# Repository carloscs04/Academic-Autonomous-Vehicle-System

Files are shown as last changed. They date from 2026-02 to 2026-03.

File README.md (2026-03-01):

# Car Controller System

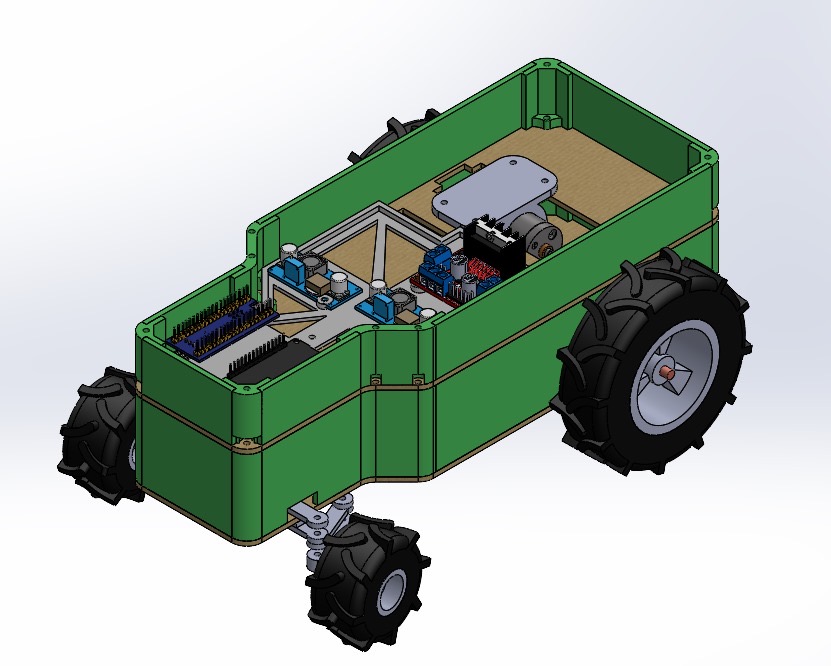
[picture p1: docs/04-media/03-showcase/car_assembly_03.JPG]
Car Assembly


---

## Academic Challenge Context

This project was developed as part of an academic robotics challenge with the following core requirements:

- 4-wheel vehicle (Ackermann or differential drive)
- At least one PID-controlled system (velocity or orientation)
- Modifiable velocity reference
- Autonomous square trajectory (X meters per side, 5 m < X < 20 m)
- 10-second stop at each waypoint
- Return to starting position
- Telemetry transmission to an external system
- Battery-powered operation
- Clean mechanical presentation

---

## Project Approach

Although the challenge did not require designing the vehicle from scratch, our team decided to build the car completely from zero for learning purposes.

This included:

- Mechanical chassis design and assembly
- Motor and driver integration
- Sensor architecture definition
- Multi-microcontroller firmware development
- Inter-board communication
- Control system implementation

The objective was to understand the system at a full engineering level rather than relying on pre-built platforms.

---

## Repository Structure

### docs/

Project documentation organized by development phase:

- research → references and background study  
- design → system architecture and decisions  
- testing → validation results  
- reports → academic deliverables  
- media → images and videos  
- development-history → progress tracking  

---

### firmware/

Embedded software for each microcontroller:

- esp32 → high-level control, navigation logic, telemetry  
- stm32 → magnetometer acquisition and sensor interface  

Each subfolder contains board-specific configuration and build instructions.

---

### hardware/

Physical system design files:

- cad → mechanical design files  

---

## System Summary

The final system integrates:

- Sensor acquisition (STM32)
- Control and navigation logic (ESP32)
- PID control implementation
- Autonomous trajectory tracking
- Telemetry transmission
- Fully battery-powered operation

The project fulfills the academic requirements while extending the implementation to a complete custom-built embedded system.

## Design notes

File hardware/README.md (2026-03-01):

# Final Mechanical Structure

This folder contains the **final validated CAD models** of the vehicle’s mechanical architecture.  
These files represent the approved structural configuration intended for manufacturing, integration, and full system validation.

This release defines the stable mechanical baseline of the project.

---

## Folder Overview

- **assembly** — Complete mechanical assemblies ready for integration and validation.
- **full_vehicle** — High-level CAD model of the entire vehicle structure.
- **parts** — Individual finalized mechanical components used in the assemblies.

---

## Design Intent

The final structure was developed considering:

- Structural stability under expected operational loads  
- Modular integration with electronics and firmware  
- Manufacturability and assembly feasibility  
- Accessibility for maintenance and testing  
- Mechanical alignment with control system requirements  

---

## Release Status

This directory represents the **approved mechanical release**.  
Experimental models and intermediate iterations are stored outside this folder.

Any modification to the structure must be version-controlled and documented.

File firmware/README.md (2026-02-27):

# Car Controller – Firmware Layer

## Overview

This directory contains all embedded firmware used in the Car Controller system.

The system is composed of two microcontrollers:

- ESP32 → High-level control and communication
- STM32 → Magnetometer acquisition and sensor interface

The firmware layer is divided by board type to clearly separate responsibilities.

---

## Architecture Overview

The system follows a distributed architecture:

ESP32
  ├─ Bluetooth gamepad interface
  ├─ Manual / Autonomous control logic
  ├─ Motor and servo control
  ├─ Ultrasonic sensing
  ├─ WiFi + MQTT telemetry
  └─ Receives heading data from STM32 via UART

STM32
  ├─ I2C communication with magnetometer
  ├─ Raw magnetic field acquisition (X, Y, Z)
  ├─ Offset calibration
  ├─ ASCII data formatting
  └─ Transmits heading data via USB CDC and UART

The STM32 acts as a dedicated sensor node.  
The ESP32 acts as the system controller.

---

## Folder Structure
firmware/
├── esp32/
│ └── Car-Controller-ESP32/
│
└── stm32/
└── Car-Controller-STM32/

Each subfolder contains:

- Source code
- Board configuration
- Peripheral setup
- Individual README

---

## Communication Flow

1. STM32 reads magnetometer via I2C.
2. STM32 applies calibration.
3. STM32 sends formatted X, Y, Z values via UART.
4. ESP32 receives heading data.
5. ESP32 uses heading for autonomous navigation.
6. ESP32 optionally sends telemetry to cloud.

---

## Design Philosophy

The firmware is divided by responsibility:

STM32 → Deterministic sensor acquisition  
ESP32 → Behavioral control and communication  

This separation improves:

- Modularity
- Debugging
- Scalability
- System clarity

---

## Development Tools

ESP32:
- Arduino IDE
- ESP32 board package
- Bluepad32
- Ubidots MQTT library

STM32:
- STM32CubeIDE
- STM32CubeMX
- HAL drivers

---

## System Capabilities

- Manual driving via Bluetooth gamepad
- Autonomous navigation using magnetometer + ultrasonic
- Encoder-based displacement measurement
- USB and UART debugging
- Cloud telemetry (optional)

---

## Future Improvements

- Refactor STM32 into modular sensor driver
- Implement non-blocking communication
- Add checksum or framing protocol between boards
- Replace ASCII with binary packet format
- Introduce PID steering control
- Separate application logic from hardware layer

---

## System Summary

The firmware layer represents the embedded core of the project.

It integrates:

- Sensor acquisition
- Control logic
- Actuation
- Communication
- Telemetry

This modular multi-MCU architecture reflects scalable embedded system design principles.

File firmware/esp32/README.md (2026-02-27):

# Car Controller – ESP32 Firmware

## Overview

This firmware runs on an ESP32 and implements a car control system with:

- Bluetooth gamepad control (Bluepad32)
- Manual and autonomous driving modes
- Ultrasonic distance sensing
- Magnetometer-based orientation control (via UART from STM32)
- Quadrature encoder feedback
- Servo steering control
- Motor PWM control
- Optional WiFi + MQTT telemetry using Ubidots

The ESP32 acts as the high-level controller of the vehicle.

---

## Hardware Requirements

- ESP32 Dev Module
- DC motor with driver stage
- Steering servo
- Ultrasonic sensor (HC-SR04 type)
- Quadrature encoder
- External STM32 (magnetometer via UART)
- WiFi network (for telemetry)

---

## Pin Configuration

| Function | GPIO |
|---|---|
| Servo | 12 |
| Ultrasonic Trigger | 14 |
| Ultrasonic Echo | 27 |
| Motor Forward | 26 |
| Motor Backward | 25 |
| Motor PWM (LEDC ch2)  | 33 |
| UART2 RX (STM32 TX) | 16 |
| UART2 TX (STM32 RX) | 17 |
| Encoder Channel A | 19 |
| Encoder Channel B | 18 |

---

## Software Dependencies

Install the following libraries in Arduino IDE:

- Bluepad32
- ESP32Servo
- UbidotsEsp32Mqtt
- ESP32 Board Support Package
- WiFi (included in ESP32 core)

---

## Functional Description

### Bluetooth Control

- Supports up to 4 controllers.
- Reads joystick axes, brake, throttle and buttons.
- Buttons toggle:
  - Automatic mode
  - WiFi telemetry
  - Autonomous start

---

### Manual Mode (Control)

In manual mode:

- Steering controlled by left joystick X-axis.
- Motor direction and speed controlled by throttle and brake.
- Encoder displacement computed.
- Optional telemetry sent to Ubidots.

---

### Autonomous Mode (Automatico)

In automatic mode:

- Ultrasonic sensor measures obstacle distance.
- Magnetometer heading received via UART.
- Proportional steering correction applied.
- Directional state machine:
  - North
  - East
  - South
  - West
- Obstacle avoidance sequence executed when needed.

---

### Sensors

#### Ultrasonic

Distance calculation:

distance = (duration × sound_speed) / 2

Sound speed constant:
0.034 cm/µs

---

#### Encoder

Quadrature decoding using interrupts.

Displacement:

displacement = (pulses / pulses_per_rev) × wheel_perimeter

---

#### Magnetometer

Data received from STM32 via UART in CSV format:

X,Y,Z

Heading calculated using:

atan2(Y, X)

Normalized to 0–360 degrees.

---

### Telemetry (Optional)

When enabled:

- Connects to WiFi
- Publishes to Ubidots:
  - Heading
  - Encoder displacement
  - Ultrasonic distance

Publishing frequency controlled by PUBLISH_FREQUENCY.

---

## Build Instructions

1. Install Arduino IDE
2. Install ESP32 board support
3. Install required libraries
4. Open Car-Controller-ESP32.ino
5. Select correct ESP32 board
6. Upload at 115200 baud

---

## Configuration Notes

- WiFi credentials are hardcoded
- Ubidots token is hardcoded
- For production use, move credentials to a separate configuration file

---

## Architecture Summary

The firmware is organized into:

- Input processing
- State management
- Control logic
- Actuation
- Optional telemetry

The ESP32 handles high-level control and communication.

---

## Known Limitations

- Uses blocking delays
- Credentials stored in plain text
- Proportional control only (no PID)
- Single-loop architecture

---

## Future Improvements

- Replace delay() with non-blocking timing
- Implement full PID control
- Move configuration to external file
- Separate tasks using FreeRTOS
- Refactor state machine for modularity

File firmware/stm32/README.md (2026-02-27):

# Car Controller – STM32 Magnetometer Firmware

## Overview

This firmware runs on an STM32F1 microcontroller and performs:

- I2C communication with a 3-axis magnetometer
- Raw magnetic field acquisition (X, Y, Z)
- Offset compensation (manual calibration gaps)
- ASCII formatting of axis data
- Data transmission via:
  - USB CDC (Virtual COM Port)
  - UART2 @ 115200 baud

The STM32 acts as a **sensor acquisition and communication layer** for the system.

---

## System Architecture Role

This firmware represents the **sensor platform layer**.

It:

1. Initializes system clocks
2. Configures I2C
3. Configures UART
4. Configures USB CDC
5. Reads magnetometer registers
6. Applies calibration offsets
7. Sends formatted data to host (ESP32 or PC)

---

## Hardware Configuration

### MCU
- Family: STM32F1xx
- Clock Source: HSE + PLL (x6)
- USB Clock: PLL
- Flash Latency: 1

---

## Peripheral Configuration

### I2C1
- Speed: 100 kHz
- Addressing Mode: 7-bit
- Used to communicate with magnetometer
- Device address: `0x1A`

Magnetometer configuration registers:
- Register `0x0B`
- Register `0x09`

---

### USART2
- Baud Rate: 115200
- 8 data bits
- 1 stop bit
- No parity
- Used for serial debugging and external communication

---

### USB Device (CDC)

- Virtual COM port interface
- Data transmitted using:

```c
CDC_Transmit_FS(mensaje, 18);

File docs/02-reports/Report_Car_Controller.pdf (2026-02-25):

# Sistema Mecatrónico para la Automatización

## Equipo 4 - Automatización Industrial

Carlos Cuadras Santaella | A01742709
Dilan Gerardo Mancilla Cruz | A00837515
Benjamín Rodríguez Limón | A01741333
Diego Alejandro Valadez Aramburo | A01710483

Profesores:
Elvira del Rosario Niño Juárez
Ricardo Esteban Roberts Ugrinovic Riccardo Cespi

i

## Contenido

## Introducción

## Descripción del reto

Se utilizaron métodos mecatrónicos para diseñar y desarrollar un sistema de automatización enfocado a optimizar un proceso industrial o de producción. En este caso se enfocó en la automatización de un vehículo no tripulado con el propósito de seguir trayectorias predeterminadas, con el objetivo de simular un tractor autónomo en un ambiente agrícola. El sistema incluyó tecnologías como control continuo de orientación, movimiento y procesamiento de datos. Esto permite al vehículo realizar las tareas asignadas de manera eficiente y sin necesidad de una intervención humana. La automatización realizada busca disminuir costos de operación y aumentar la eficiencia en la producción agrícola.

## Socio Formador

John Deere es una marca estadounidense reconocida por la fabricación de maquinaria agrícola, maquinaria pesada y por ser una compañía líder en la innovación y desarrollo agrícola. Fundada en 1837 por John Deere, un herrero pionero en el equipo agrícola. Hoy en día, no solo se destacan por la robustez y fiabilidad de sus productos, sino también por su constante innovación y compromiso con la sustentabilidad.
La empresa sigue siendo un referente global en la mejora de la productividad agrícola y la sostenibilidad.

## Alcance y entregables

Se deberá entregar un vehículo autónomo funcional a escala, controlado por un sistema PID implementado en uno o múltiples microcontroladores para realizar el procesamiento de señales recabadas por un sistema sensorial como las entradas de este. Esto se realizará integrando diferentes tecnologías y metodologías, como diseño CAD, impresión 3D, corte láser, electrónica y programación.

## Propuesta inicial de solución

## Componentes mecánicos

Los componentes mecánicos son cien por ciento diseñados y manufacturados por nosotros, ya que se decidió crear todo el aspecto mecánico desde cero. Esto para poder tener libertad creativa y de modificar nuestra estructura principal para asegurar un funcionamiento optimo en las condiciones deseadas. Además de asegurar un que nuestro sistema electrónico estuviera resguardado para poderse usar en un ambiente expuesto en la naturaleza.

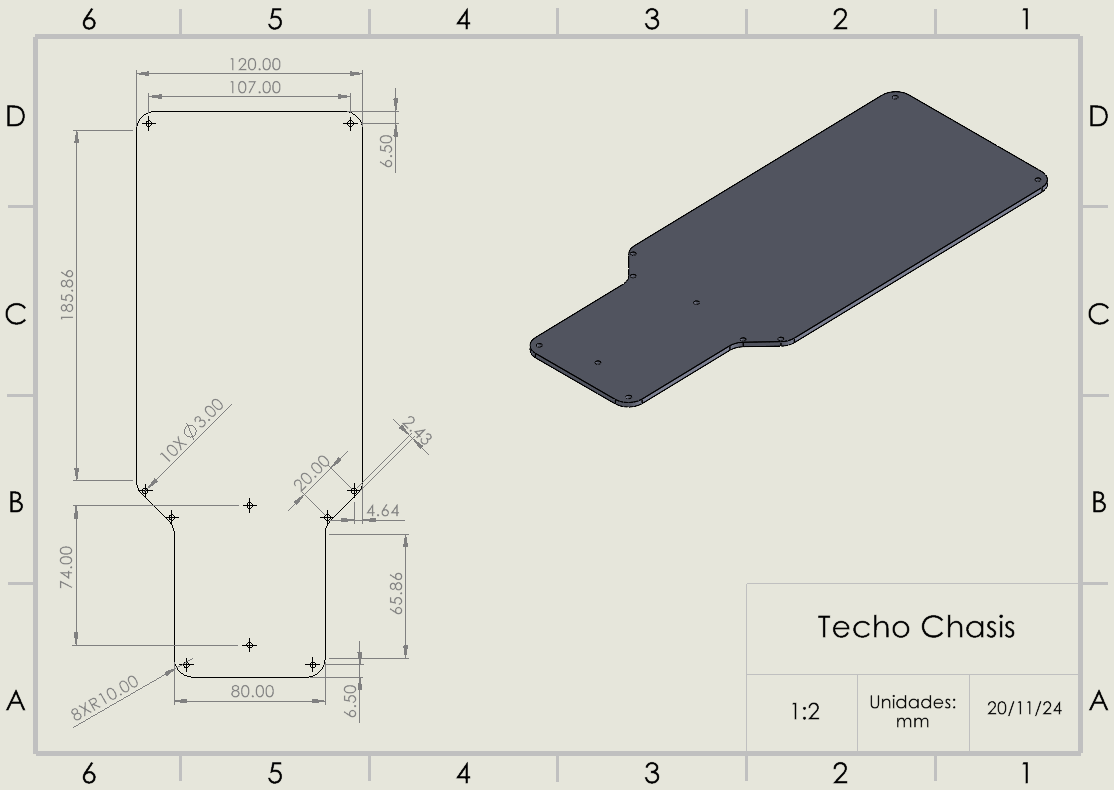
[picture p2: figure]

Ilustración 1 Chasis (techo)

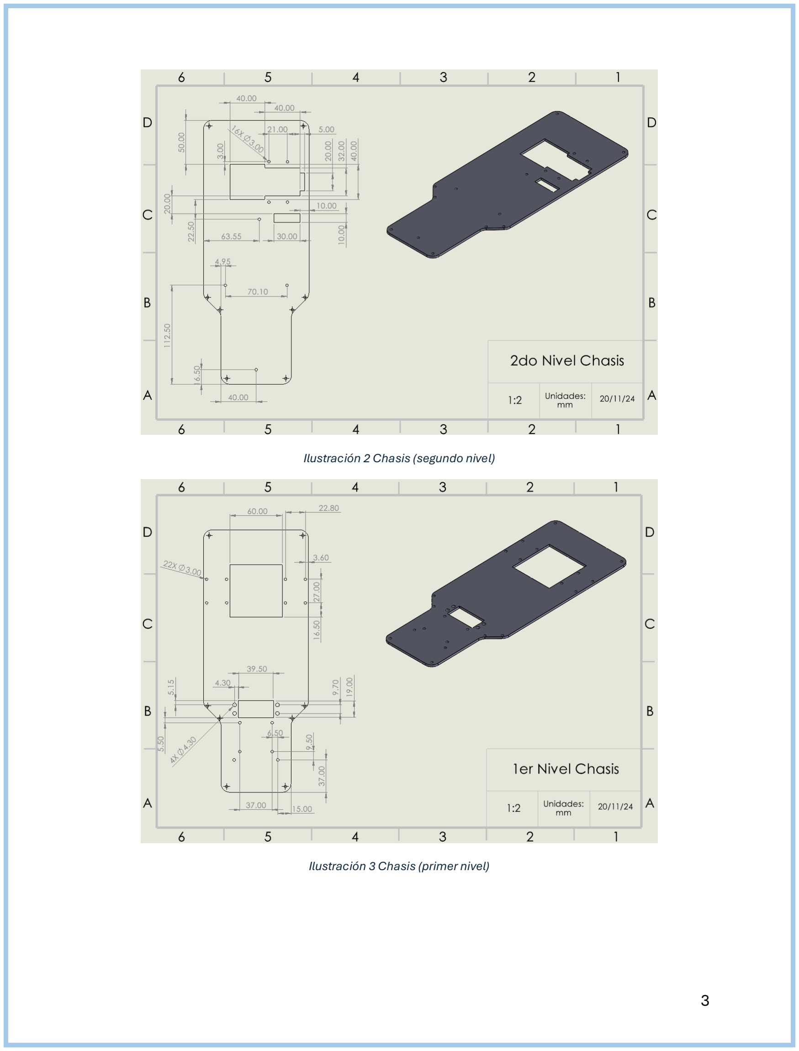
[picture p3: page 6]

Ilustración 2 Chasis (segundo nivel)

Ilustración 3 Chasis (primer nivel)

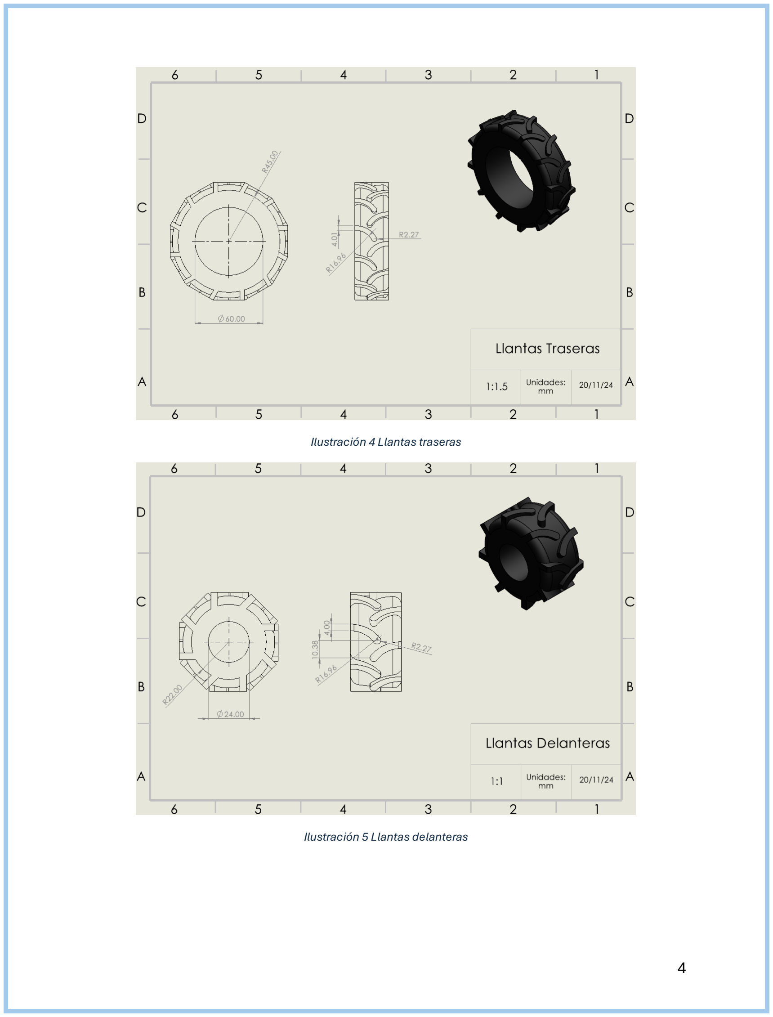
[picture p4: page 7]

Ilustración 4 Llantas traseras

Ilustración 5 Llantas delanteras

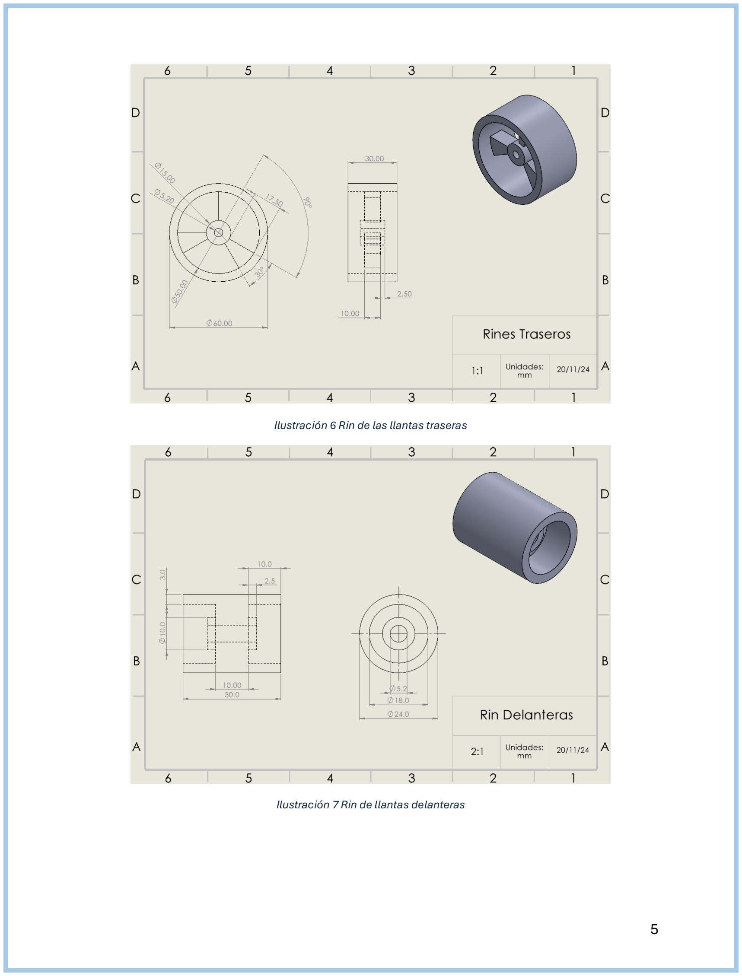
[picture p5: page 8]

Ilustración 6 Rin de las llantas traseras

Ilustración 7 Rin de llantas delanteras

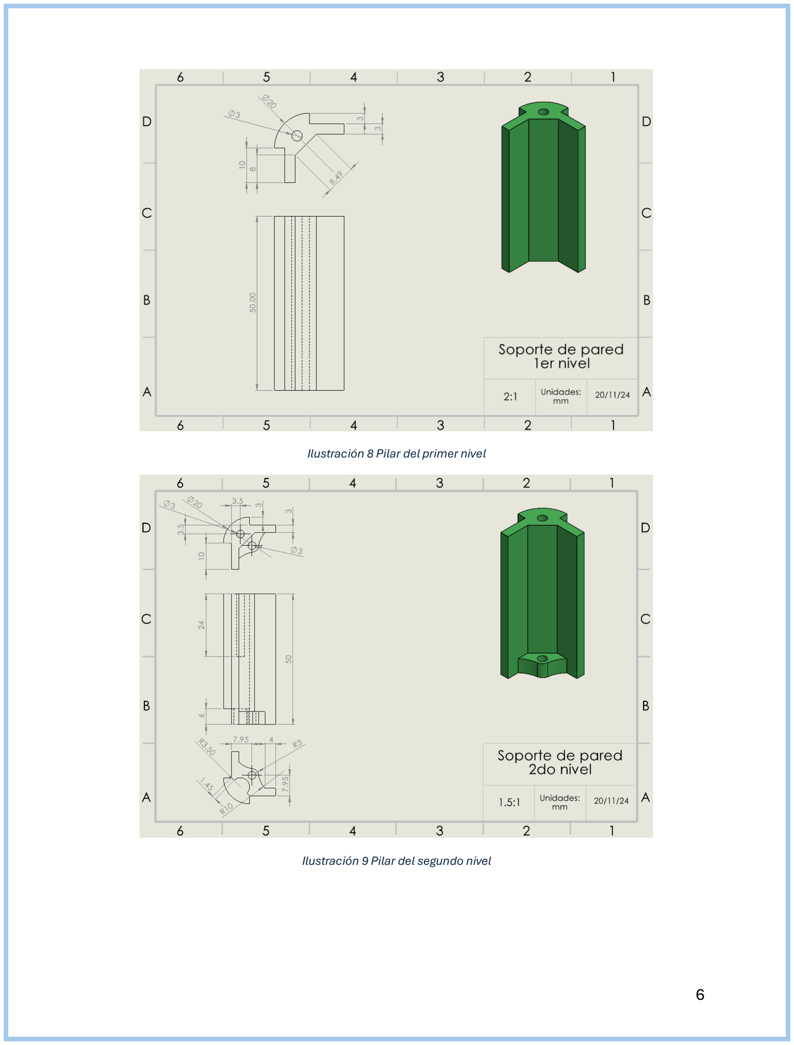
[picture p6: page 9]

Ilustración 8 Pilar del primer nivel

Ilustración 9 Pilar del segundo nivel

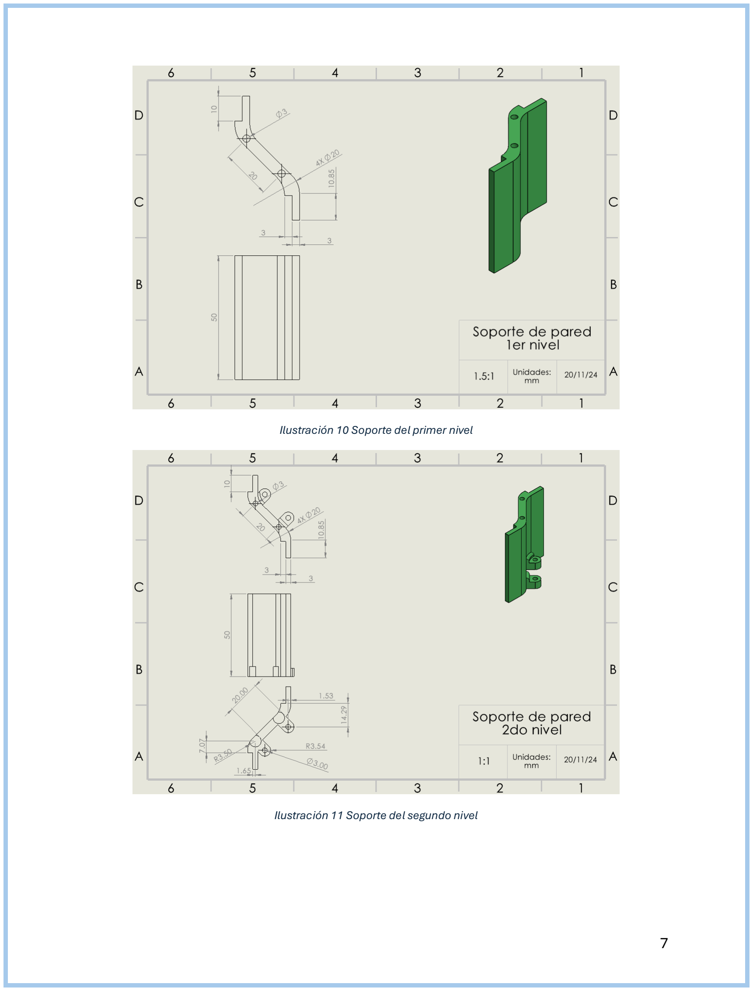
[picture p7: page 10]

Ilustración 10 Soporte del primer nivel

Ilustración 11 Soporte del segundo nivel

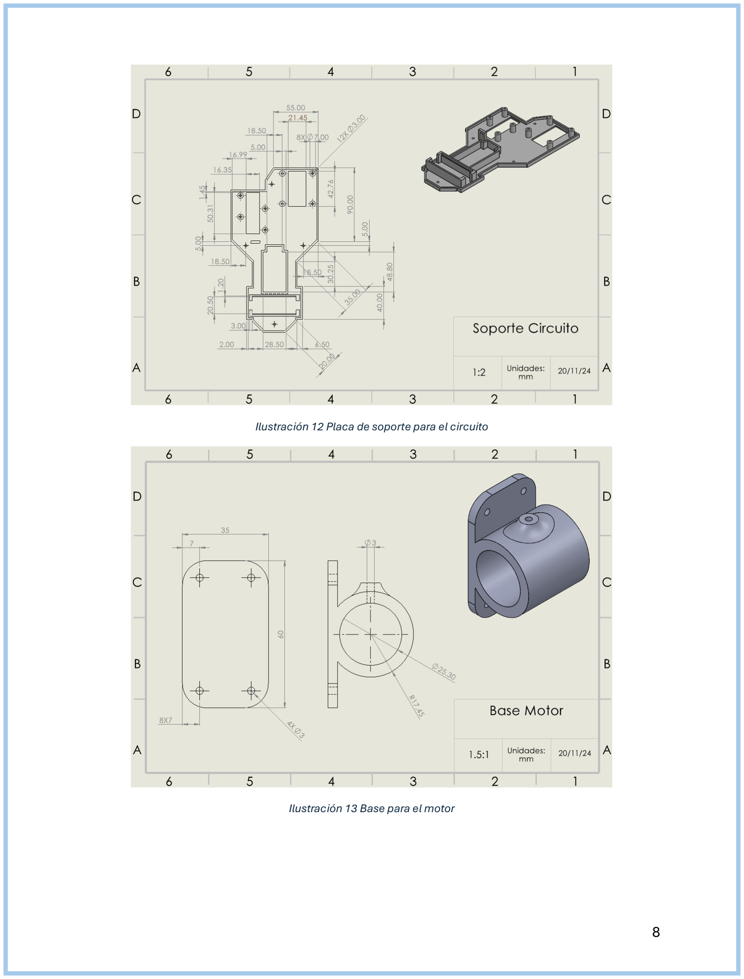
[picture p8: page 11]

Ilustración 12 Placa de soporte para el circuito

Ilustración 13 Base para el motor

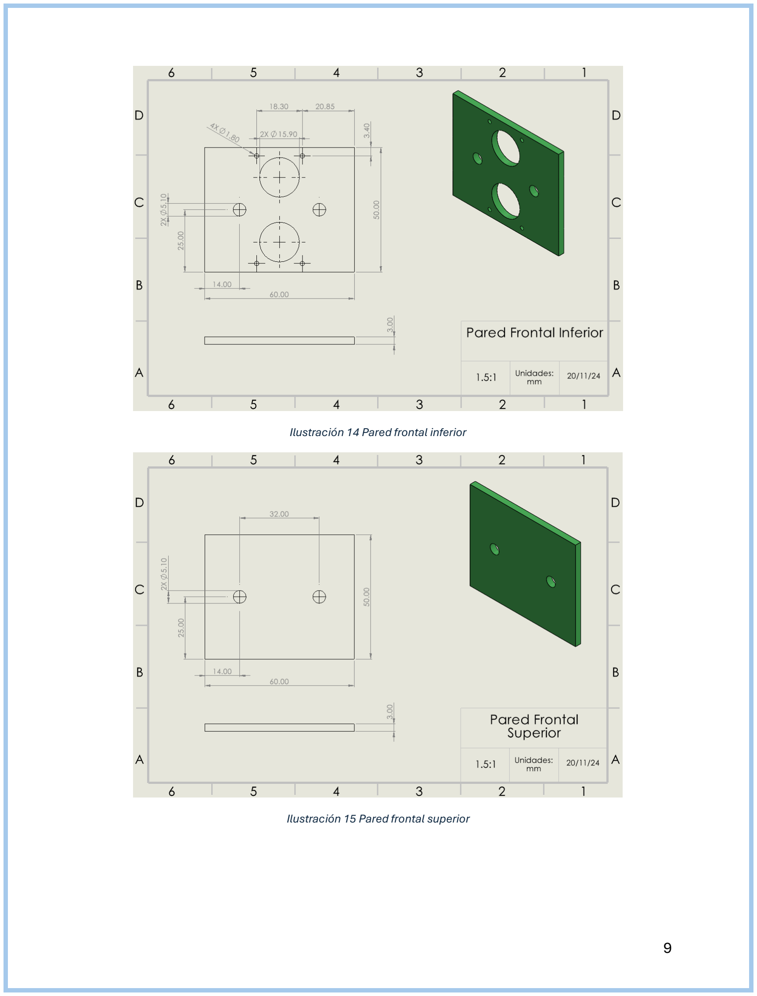
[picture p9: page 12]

Ilustración 14 Pared frontal inferior

Ilustración 15 Pared frontal superior

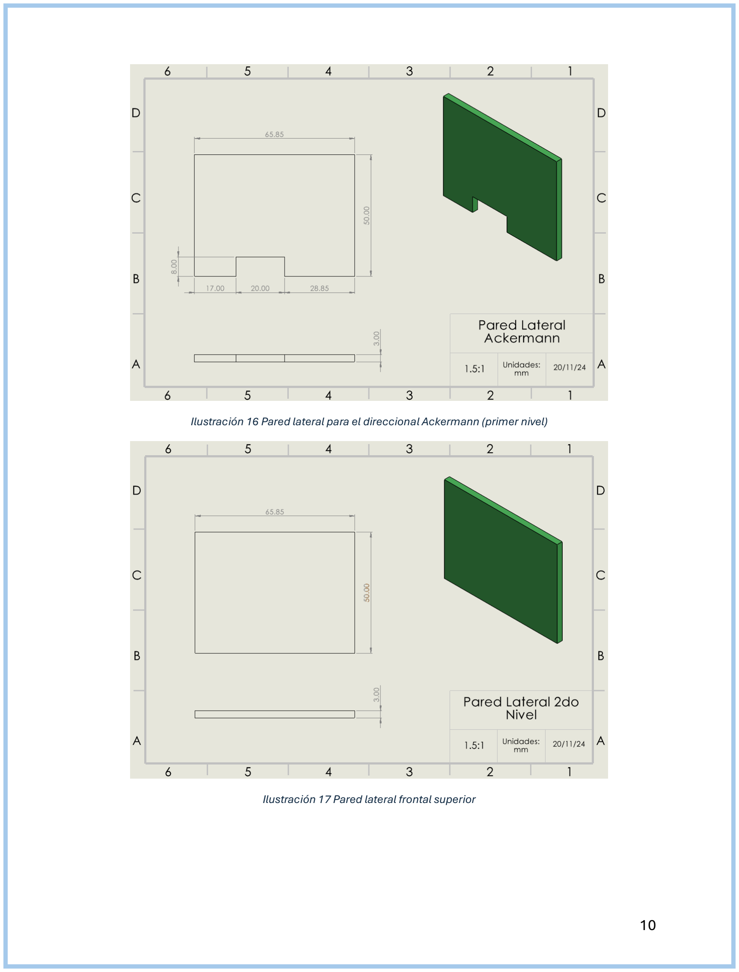
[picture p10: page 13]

Ilustración 16 Pared lateral para el direccional Ackermann (primer nivel)

Ilustración 17 Pared lateral frontal superior

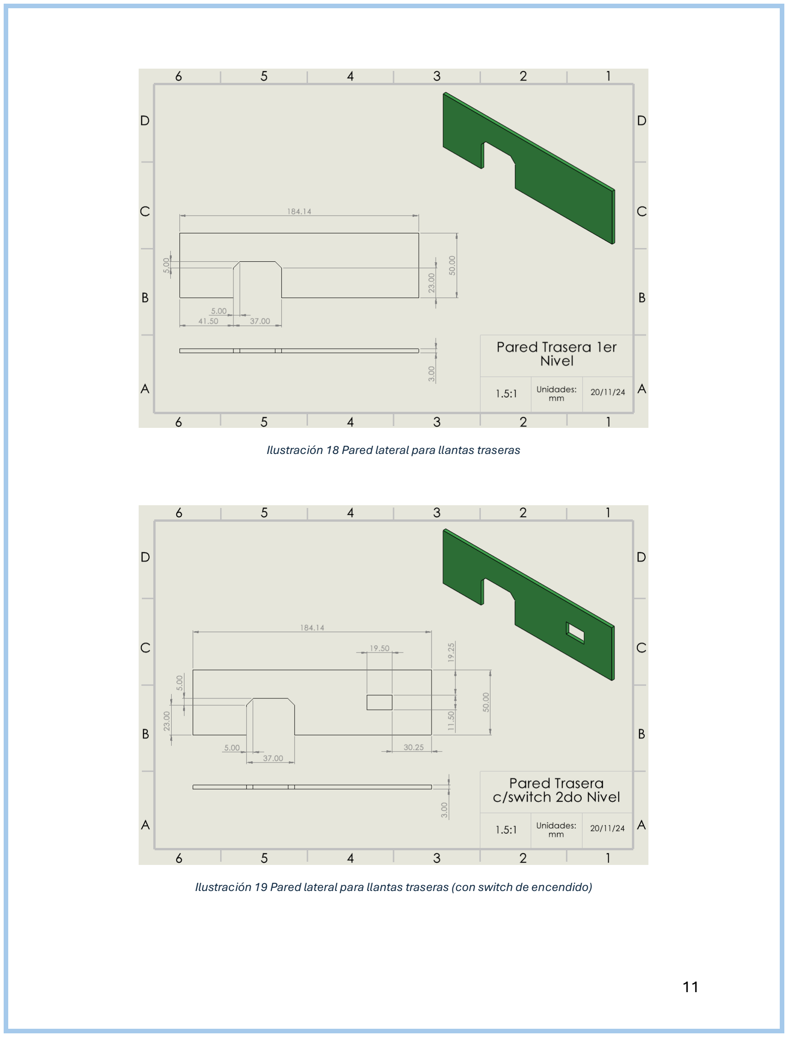
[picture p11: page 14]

Ilustración 18 Pared lateral para llantas traseras

Ilustración 19 Pared lateral para llantas traseras (con switch de encendido)

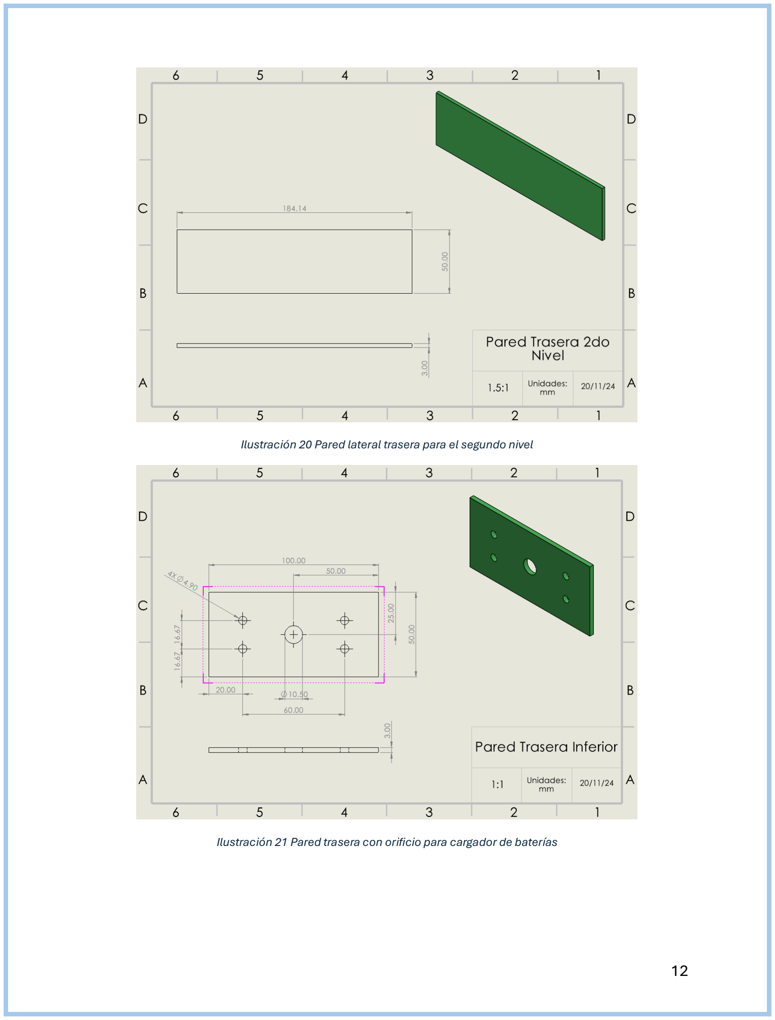
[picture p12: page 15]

Ilustración 20 Pared lateral trasera para el segundo nivel

Ilustración 21 Pared trasera con orificio para cargador de baterías

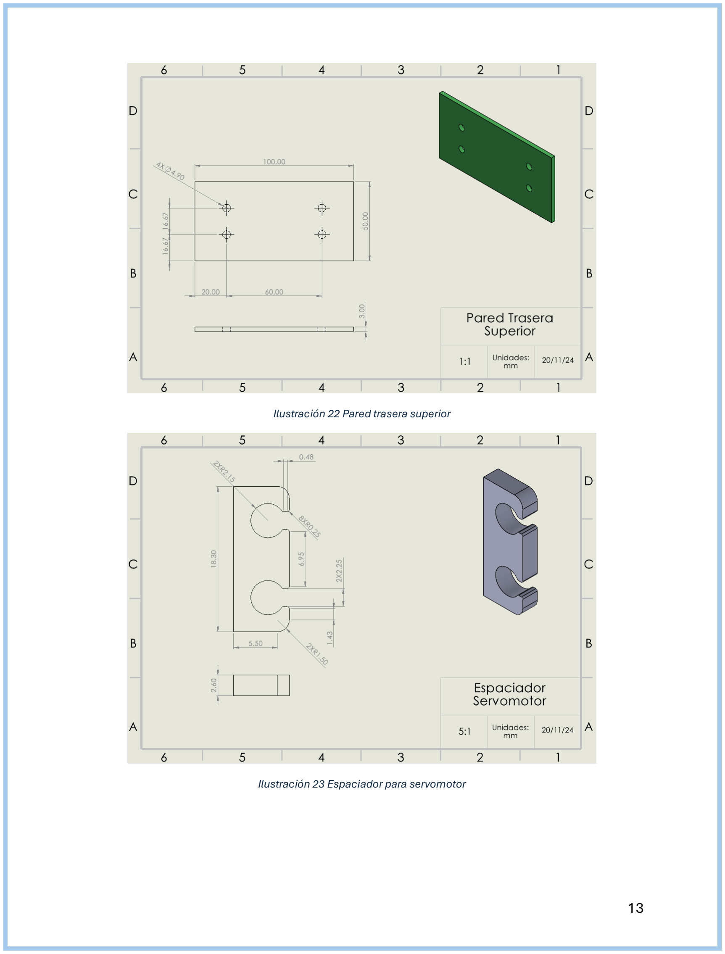
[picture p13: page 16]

Ilustración 22 Pared trasera superior

Ilustración 23 Espaciador para servomotor

Ilustración 24 Soporte para biela del direccional Ackermann

Ilustración 25 Biela del Ackermann (conectora del servomotor con las llantas)

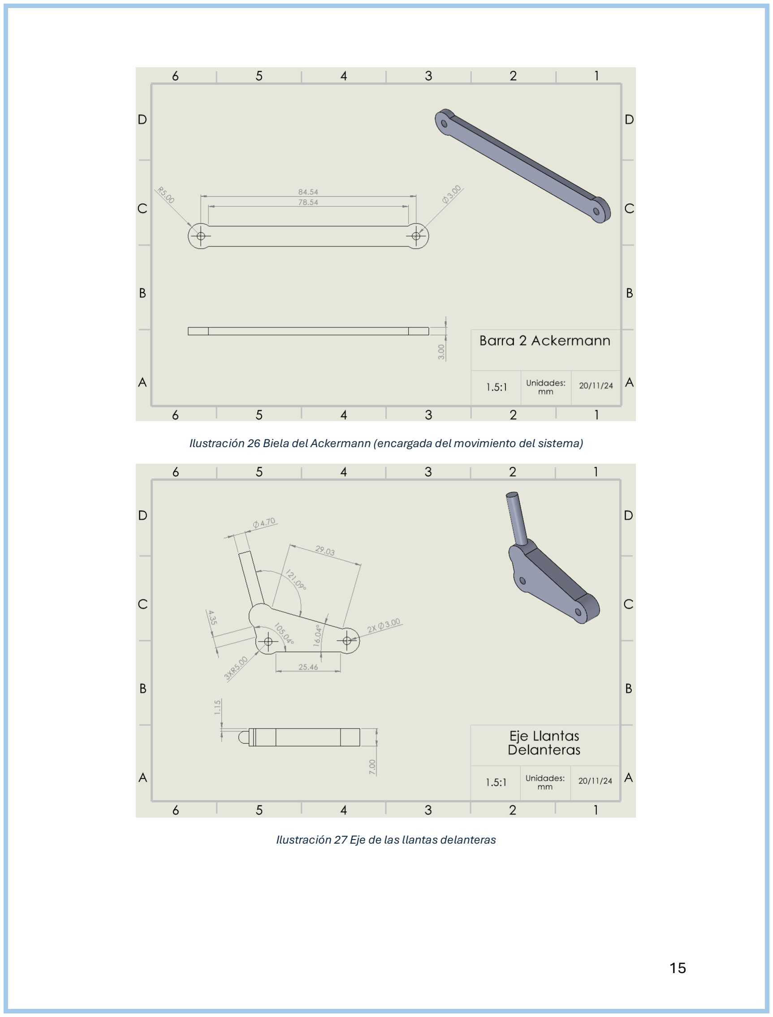
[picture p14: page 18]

Ilustración 26 Biela del Ackermann (encargada del movimiento del sistema)

Ilustración 27 Eje de las llantas delanteras

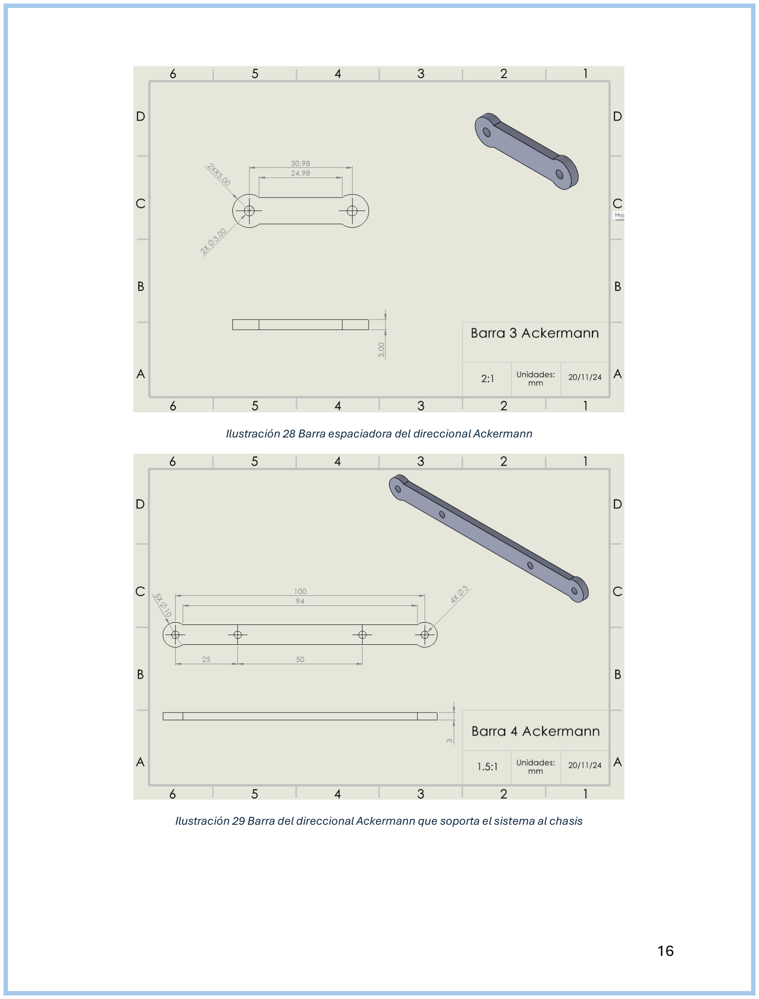
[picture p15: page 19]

Ilustración 28 Barra espaciadora del direccional Ackermann

Ilustración 29 Barra del direccional Ackermann que soporta el sistema al chasis

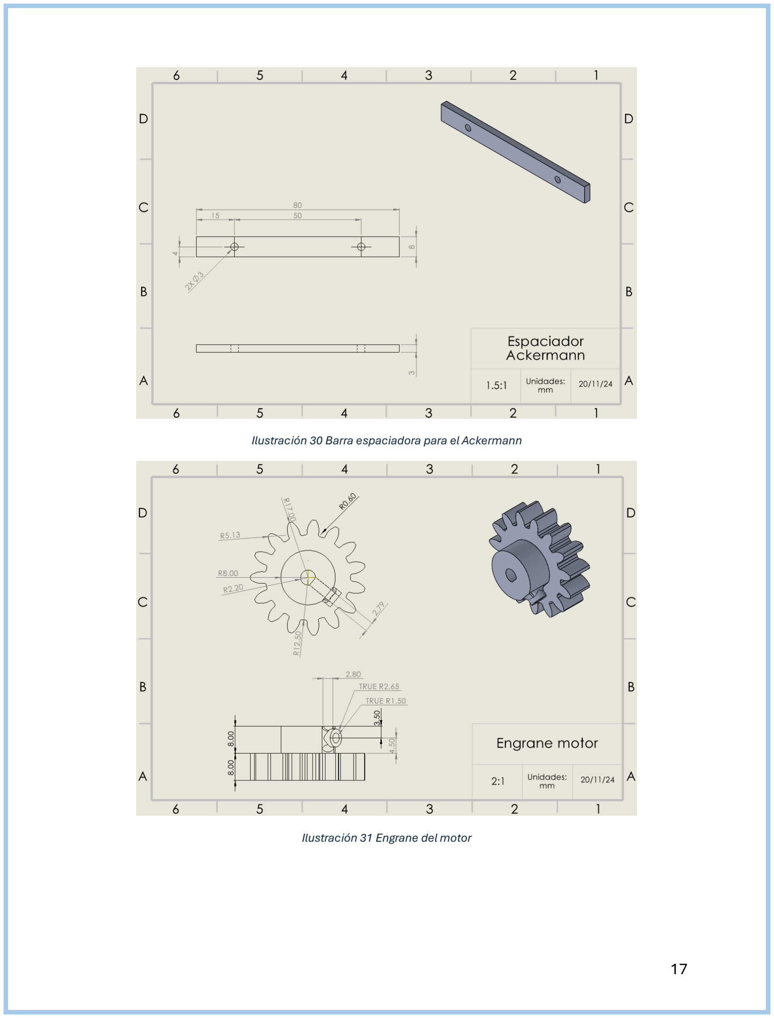
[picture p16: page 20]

Ilustración 30 Barra espaciadora para el Ackermann

Ilustración 31 Engrane del motor

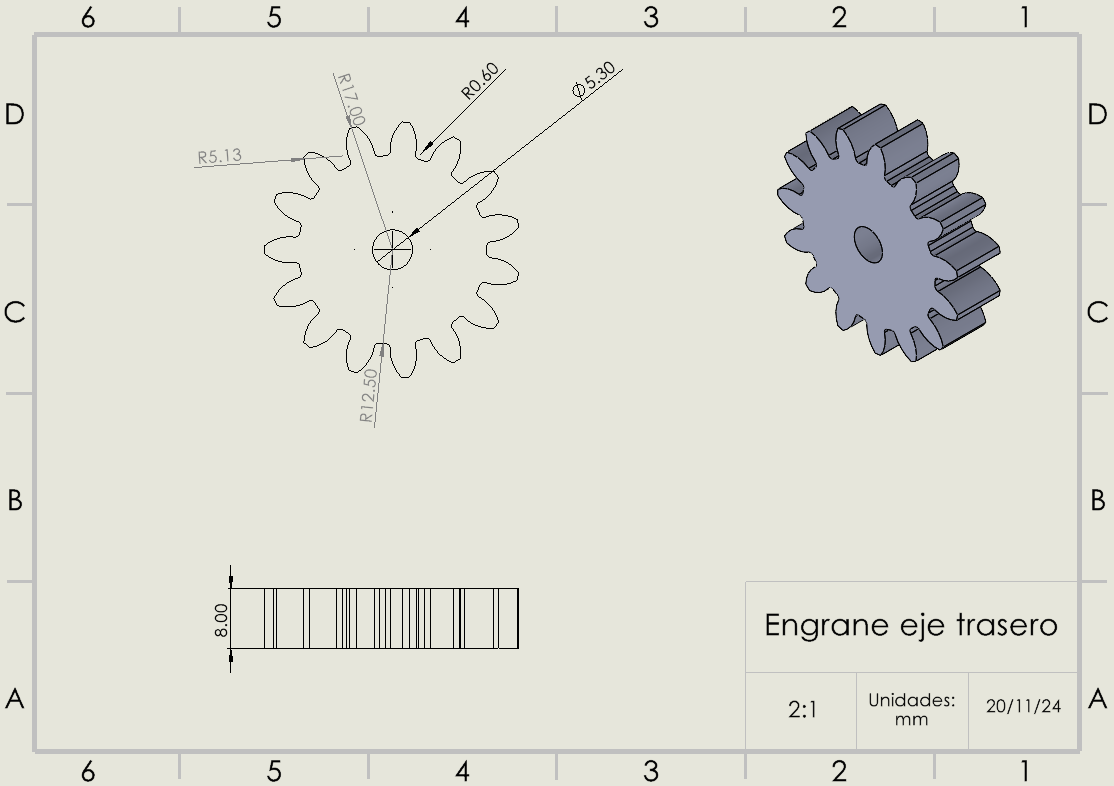
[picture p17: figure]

Ilustración 32 Engrane del eje trasero

## Componentes electrónicos

Imágenes de los sensores y esquemáticos Sensores implementados
- Sensor ultrasónico HC-SR04:

- Magnetómetro HMC5883L:
- Encoder integrado y motor DC de 12V:
- Microcontrolador STM32F103C8T6:
- Servomotor SG5010:

- Microcontrolador ESP32:

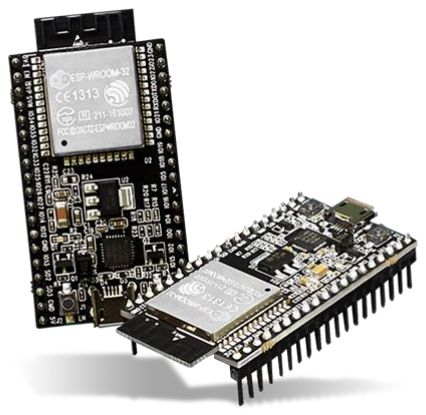
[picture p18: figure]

- Batería recargable de 12 V - 5600 mAh:
- Regulador de voltaje LM2596:
- Puente H L298N

## Desarrollo del proyecto

## Definición del proyecto y desarrollo de la propuesta

Como se mencionó anteriormente, el objetivo de este proyecto es crear un vehículo no tripulado funcional a escala, integrado con tecnologías que le permitan navegar en un entorno agrícola en base a puntos predeterminados de manera eficiente. Se busca desarrollar un vehículo robusto en su funcionamiento y en su aguante, para que pueda resistir las condiciones de trabajo duras como lo son las del sector agrícola. Por lo que, como primera idea, se deseó crear un diseño propio para tener libertad creativa de diseño, para asegurar que nuestro dispositivo cumpliera las expectativas de nuestro socio formador.

## Desarrollo de diseño conceptual

Durante la etapa temprana del proyecto, se tuvo la idea de que nuestro vehículo no tripulado tuviera la mayor semejanza posible a un tractor John Deere por varias razones:

- Facilitar la visibilidad de la marca
- Aprovechar avances mecánicos y espaciales que tiene un tractor, como la estabilidad que brinda tener una base ancha y un centro de masa bajo en terrenos irregulares como lo es el campo
- Proporcionar seguridad a la parte de la electrónica, protegiéndola con una carcasa robusta.
Una vez definido nuestro diseño ideal por medio de bocetos, nos aseguramos de que hubiera el espacio suficiente para acomodar correctamente todos nuestros sistemas integrados en el vehículo, como sensores, actuadores, fuentes de poder y procesamiento.

Especificaciones técnicas
Se utilizaron distintos materiales para la fabricación de la estructura del vehículo, como PLA, TPU, MDF y varillas de cobre.
El PLA se utilizó en impresión 3D para crear piezas rígidas que funcionarían como parte de la estructura rígida, como soportes para los componentes encargados del movimiento y la dirección como el servomotor y el motor DC, además de toda la electrónica. Este material se decidió utilizar para esta aplicación ya que es resistente y ligero. Se utilizó una impresora 3D con tolerancias de ±0.2mm.
El TPU se utilizó para la impresión de los neumáticos del vehículo, ya que se consideró que este material daría suficiente tracción para que este se desplazara de manera correcta. Igualmente se utilizó una impresora con tolerancias de ±0.2mm.
El MDF se utilizó para crear las cubiertas de los tres niveles del vehículo (primer nivel o chasis, segundo nivel y el techo o cubierta), además de las paredes que cubren el vehículo en su totalidad. Al igual que con el PLA, este material se eligió por su alta resistencia y bajo peso. Para el corte de estas piezas se utilizó una cortadora laser con tolerancias de ±0.2mm.
La varilla de cobre fue utilizada como eje de las llantas traseras, para transmitir la potencia de manera adecuada del motor a estas.
Además, se utilizaron materiales varios para asegurar componentes electrónicos a la carrocería, como cinta adhesiva doble cara, cinta aislante y cinchos plásticos.

Definición de las funciones
Nuestro dispositivo, un prototipo de un tractor autónomo a escala cuenta con diferentes conjuntos de componentes que cuentan con una función en específico. Todas estas funciones son una parte de un sistema que tiene como objetivo cumplir la función principal del dispositivo, la cual es hacer una trayectoria de manera autónoma en un espacio designado. En nuestro tractor a escala contamos con cinco áreas principales, que funcionan como pilares para nuestro objetivo principal. Estas funciones son:
- Direccional Ackermann
- Potencia de la tracción trasera
- Potencia eléctrica
- Electrónica para obtención de datos

- Electrónica para procesado y envío de datos
La primera función principal es la direccional Ackermann, la cual como su nombre lo indica, se encarga de dirigir el vehículo en la dirección deseada por medio de un servomotor de 180°, el cual es controlado por uno de los microcontroladores.
La segunda función es la de la potencia tracción trasera del vehículo, esta está conformada por un motor de corriente directa, una barra de cobre que sirve como eje de los dos neumáticos traseros y un par de engranes, que sirven para transmitir la potencia del motor al eje. El motor DC también se encuentra controlado por uno de los microcontroladores.
La potencia eléctrica está conformada por una batería recargable de 12 volts, junto con sus respectivas conexiones que alimentan a todos los componentes del vehículo.
La electrónica se separa en dos principales funciones, obtención de datos (sensores) y procesado y envío de datos (microcontroladores que reciben señales sin procesar y dan una señal de salida para accionar un actuador).
El sistema de sensores está conformado por un encoder del cual conseguimos el desplazamiento angular de eje. Tras el procesamiento de esta señal, podemos conseguir el desplazamiento lineal del vehículo en sí. Además, contamos con un magnetómetro del cual obtenemos la dirección del tractor con respecto al norte magnético de la tierra en grados.
Los microcontroladores utilizados en el vehículo son dos; un STM32F1 bluepill y un ESP32 DevKit. El STM32F1 se utiliza exclusivamente para la lectura del magnetómetro, la cual es enviada al ESP para luego ser procesada por medio de algoritmos de control. El ESP se encarga de mandar una señal al servomotor del direccional Ackermann, buscando mantener el mismo ángulo en su trayectoria. Si el magnetómetro da una lectura inadecuada (fuera de la trayectoria) el ESP mandará una señal al servomotor ordenándole corregir ese error, volviendo de nuevo a la trayectoria deseada y continuando con su recorrido establecido.

## Ingeniería de detalle

Presenta los detalles específicos del diseño, como diagramas, planos, cálculos y análisis.
Diagrama eléctrico

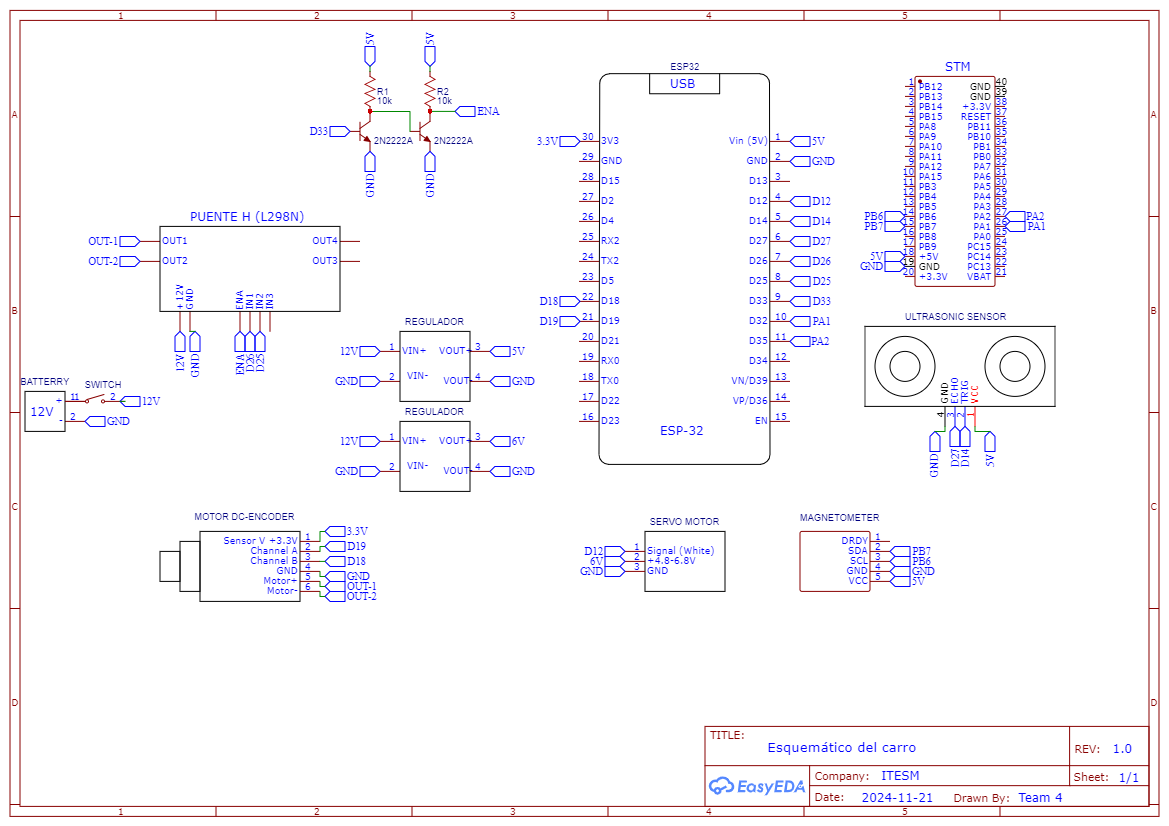
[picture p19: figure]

Sintonización del PID

Explicación del lazo de control:
En cuanto al lazo de control que se estableció para realizar el modelo del reto, se utilizó un modelo aproximado de segundo orden a una salida rampa en el sistema A/ (BS^2+CS) (Investigar modelo del JAW del carro con respecto a una entrada escalón), en este sentido, analizando el modelo de la planta propuesto se requirió diseñar un controlador de tipo proporcional en el sistema. El tipo de sistema con el que se comporta este sistema es de estabilización dado que tiene un polo en el origen, es por ello, que es importante reconocer que una sintonización por método integrativo sería un problema debido a la aparición de dos ceros en el origen.

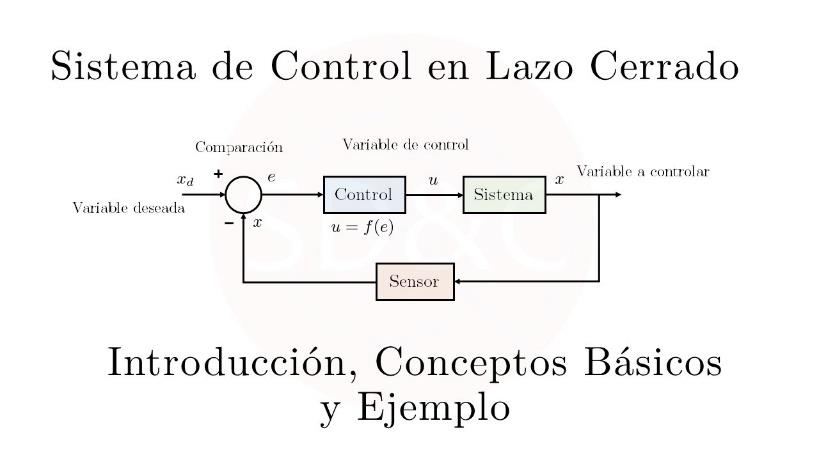
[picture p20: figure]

En cuanto a la aplicación de la programación en el carrito se realizó por medio de calcular el error con base a una Kp que se utilizó realizando un método de sintonización.

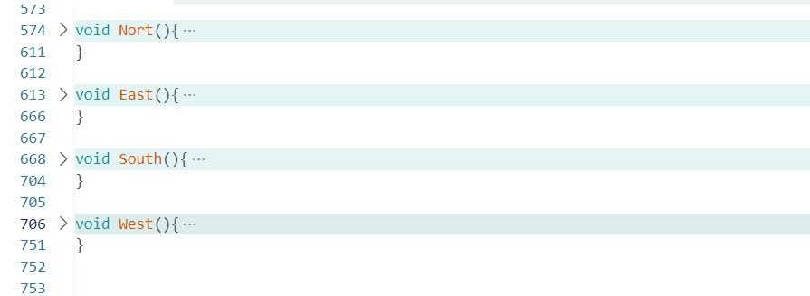
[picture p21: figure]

En este sentido se definieron 4 funciones correspondientes a los ejes coordenados en donde el carrito se desplazaría.

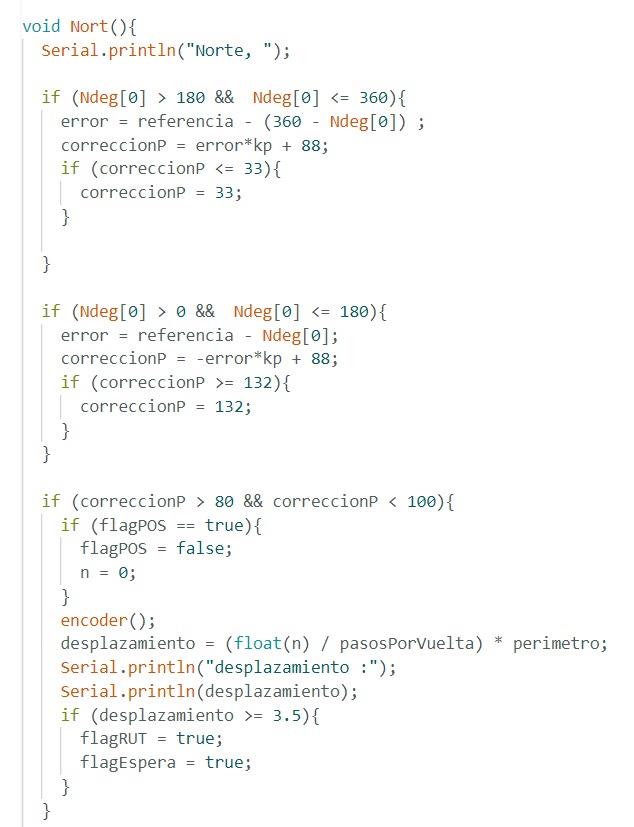
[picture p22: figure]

Para ello, se utilizan dos condicionales, la primera que es para restringir la acción proporcional sobre un servomotor y así poder reducir el error correspondiente a la medición comparándolo con la referencia. Es por ello por lo que, se utilizan estas dos funciones para obtener todas las posibles opiniones.

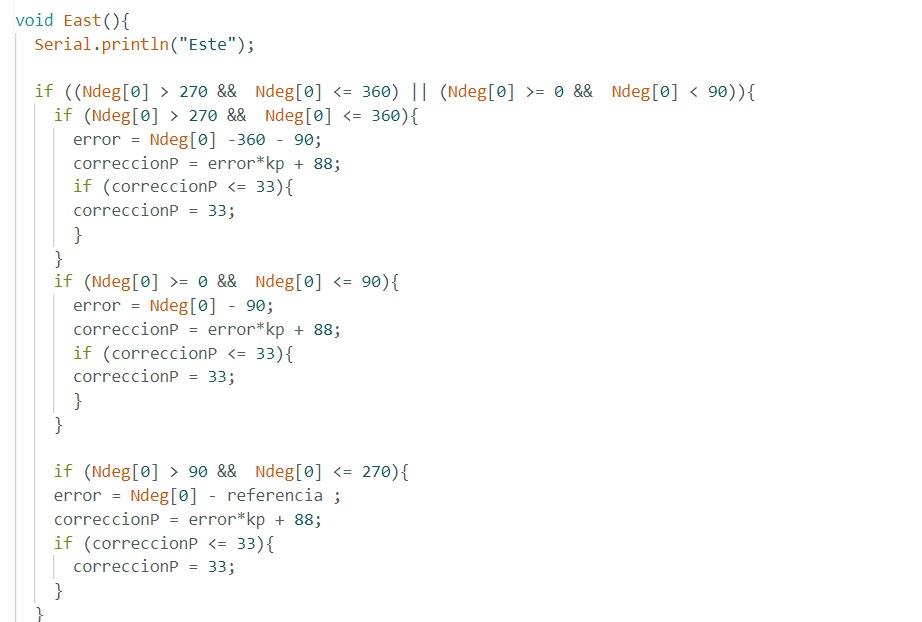
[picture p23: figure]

En este sentido el código es similar a los anteriores y posteriores apartados respectivos debido al uso de la misma lógica. Sin embargo, es necesario realizar una trayectoria en la que el control pueda predecir y controlar los sucesos que ocurren en la planta.

## Implementación y Evaluación

## Desarrollo del prototipo

Se comenzó el ensamble de nuestro prototipo una vez que todas las piezas estaban elaboradas. Se utilizó como regla en nuestro diseño utilizar tornillos M3, esto para facilitar el diseño y la adquisición de nuestros materiales.
Primero se instaló en el chasis las chumaceras del eje trasero, el direccional Ackermann y la base de nuestro servomotor. Todo esto con tornillos M3 y sus respectivas tuercas. Además, se aseguró la batería que sería nuestra fuente de poder para todo el sistema con cinta doble cara en el centro geométrico del chasis para asegurar que el centro de gravedad estuviera lo más cerca posible del suelo.
Después de fijar todos los componentes del primer nivel, se instalaron las paredes del primer nivel, que además sirven como soportes para el segundo. Luego, se puso la base del segundo nivel y encima de este, los componentes correspondientes los cuales eran: el soporte del motor que potenciaría el vehículo y la placa donde iría montado el circuito.

Luego, se instalaron las paredes para el segundo nivel, junto con el techo que cubriría todo el proyecto, protegiéndolo de cualquier imprevisto u accidente.
Cabe resaltar que todas las piezas antes mencionadas fueron unidas entre sí con tornillería M3. Los cables eléctricos fueron asegurados con cinchos plásticos, cinta de aislar y cinta doble cara.

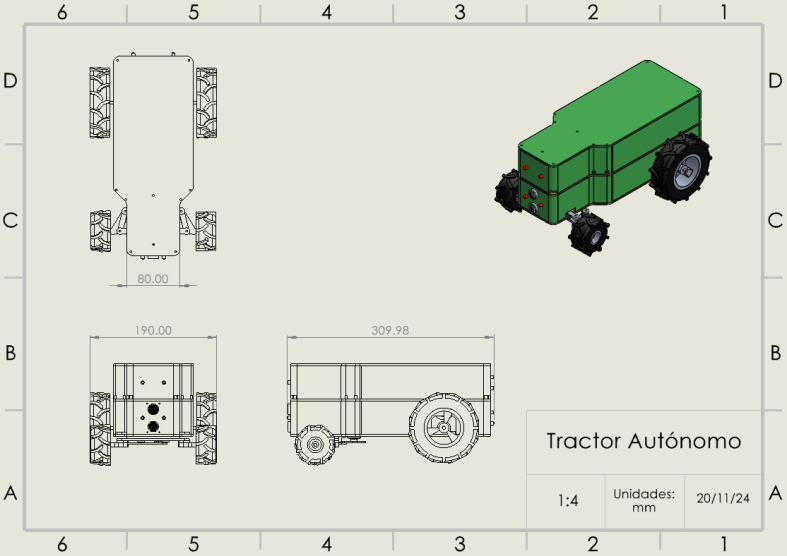
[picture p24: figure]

Ilustración 33 Ensamble de Tractor Autónomo

## Validación de funcionalidad

Nuestro prototipo es sometido a una prueba con las condiciones establecidas en un principio. Durante esta prueba, debe de recorrer un mínimo de cinco metros por lado de una trayectoria cuadrada, además de detenerse durante 10 segundos al finalizar cada tramo recto que haga. También, nuestro prototipo debe reaccionar ante perturbaciones y obstáculos que aparezcan durante el camino, manteniendo siempre su trayectoria para finalmente llegar al punto de donde partió, solamente basándose en los datos recibidos de los sensores (magnetómetro y encoder).

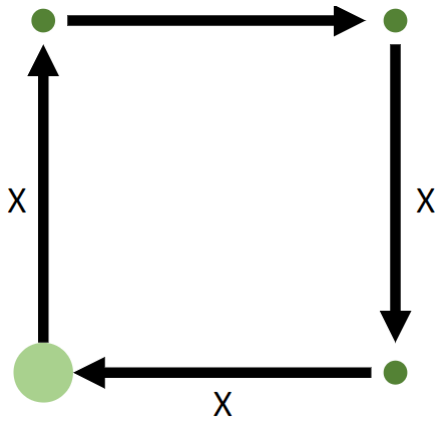
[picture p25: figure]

Ilustración 34 Trayectoria esperada del prototipo
Al realizar la prueba en nuestro prototipo observamos que sigue la trayectoria de manera muy precisa, teniendo muy poco error en cada uno de los tramos rectos. Este recorrido es realizado en base a la información recibida de los sensores, y observamos que si logra llegar al lugar donde comenzó este recorrido, pero con un error. Se logra observar el error ya que hay un ligero desfase entre el lugar donde empezó el tractor y donde terminó, esto se debe a la acumulación del error durante cada tramo del circuito.
Podemos concluir satisfactoriamente que nuestro prototipo cumple con su objetivo, pero existe un área de mejor aún, que es la precisión del recorrido, minimizando el error durante el circuito.

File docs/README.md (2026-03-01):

# 📚 Documentation Structure

This folder contains all project documentation, organized to clearly separate final deliverables, development trajectory, and visual evidence.  
The structure is designed to ensure traceability, clarity, and professional-level documentation.

## Folder Overview

- **research** — Final research and technical references supporting the project.
- **design** — Consolidated system and component design documentation.
- **testing** — Validated testing plans, results, and conclusions.
- **reports** — Formal reports and project summaries.
- **media** — Visual documentation of development, validation, and presentation.
- **development-history** — Complete chronological record of the project’s evolution.

---

## 1. Research

This folder contains the **final versions** of research materials that support the project.

It includes:
- Literature reviews
- Technical references
- Benchmarking studies
- Feasibility analyses

Only consolidated and relevant research is stored here.  
Exploratory notes, discarded references, and early hypotheses are documented in `development-history`.

---

## 2. Design

This folder contains the **finalized design documentation** of the project.

It includes:
- System architecture
- Mechanical design definitions
- Electrical schematics
- Control strategies
- Design justifications

Only approved or implemented designs are stored here.  
Design iterations, alternative concepts, and rejected solutions are tracked in `development-history`.

---

## 3. Testing

This folder contains **validated testing documentation**.

It includes:
- Test plans
- Experimental setups
- Performance metrics
- Final validation results
- Test conclusions

Intermediate experiments, tuning attempts, and failed tests are documented in `development-history`.

---

## 4. Reports

This folder contains **formal project documentation** prepared for academic, industrial, or presentation purposes.

It includes:
- Technical reports
- Project summaries
- Executive or final reports
- Deliverables submitted to stakeholders

---

## 5. Media

This folder contains **visual documentation** of the project and is organized into three categories:

### development
Photos and videos documenting the different stages of construction, integration, and iteration.

### validation
Visual evidence of testing procedures, experiments, and system performance.

### showcase
High-quality media intended for demonstrations, portfolios, and public presentation.

---

## 6. Development History

This folder documents the **complete trajectory of the project** from initial concept to final implementation.

It includes:
- Design iterations
- Decision logs
- Failed attempts and lessons learned
- Technical pivots
- Chronological development notes

This section functions as an engineering logbook, ensuring traceability between early ideas and final deliverables.

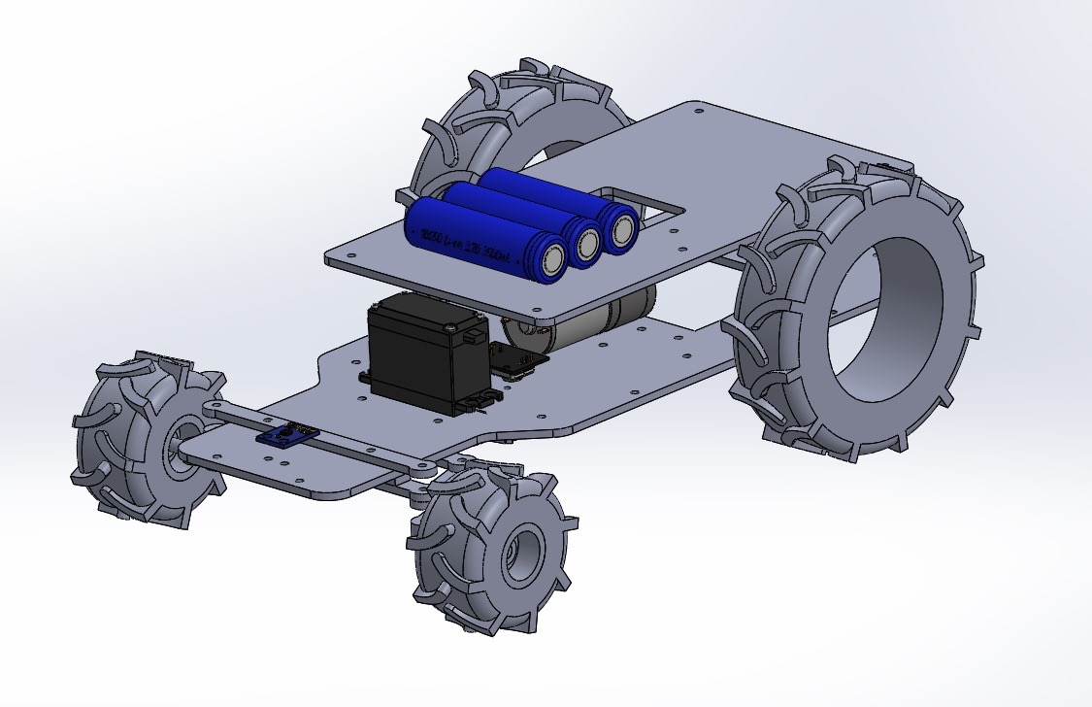
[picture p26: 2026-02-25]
docs/04-media/01-development/mechanical-prototype/attempt-03/cad_second_floor_01.JPG

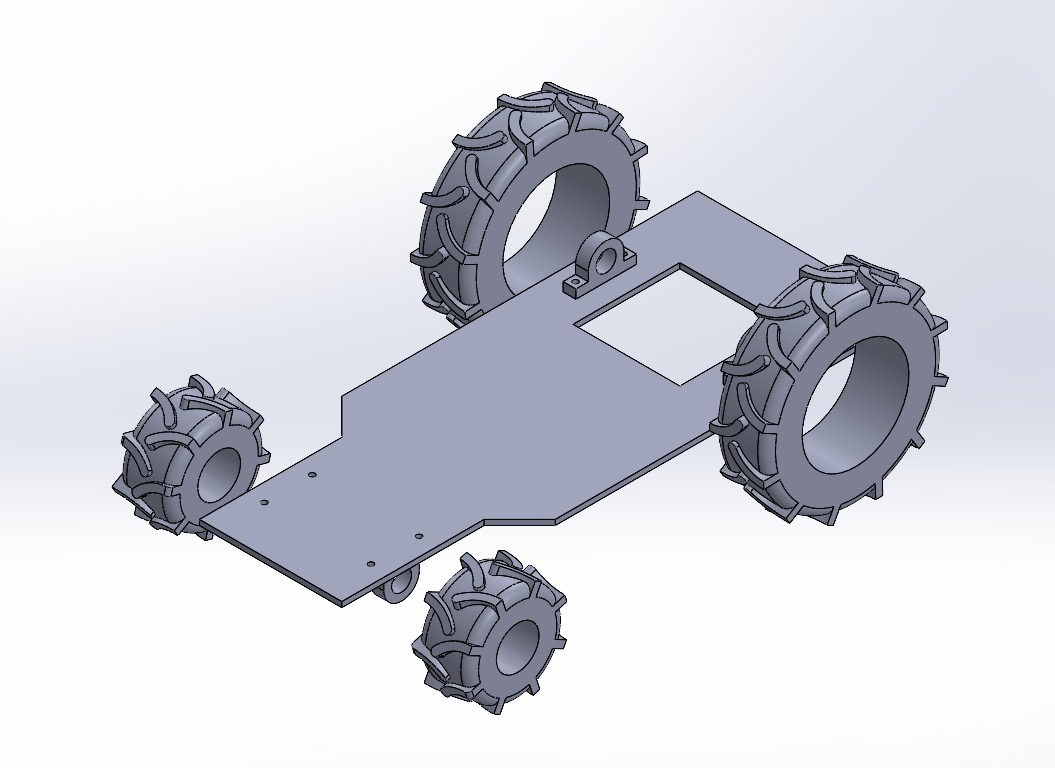
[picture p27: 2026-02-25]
docs/04-media/01-development/mechanical-prototype/attempt-01/car_wheels.JPG

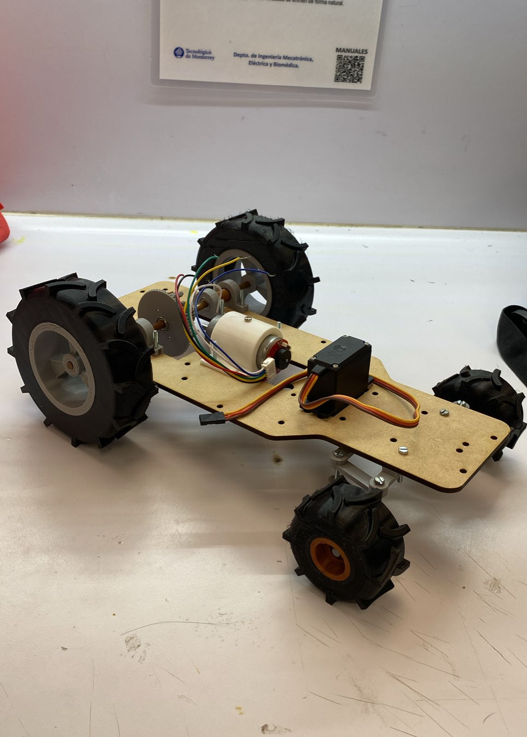
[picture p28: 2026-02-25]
docs/04-media/01-development/mechanical-prototype/attempt-02/car_first_floor_01.JPG

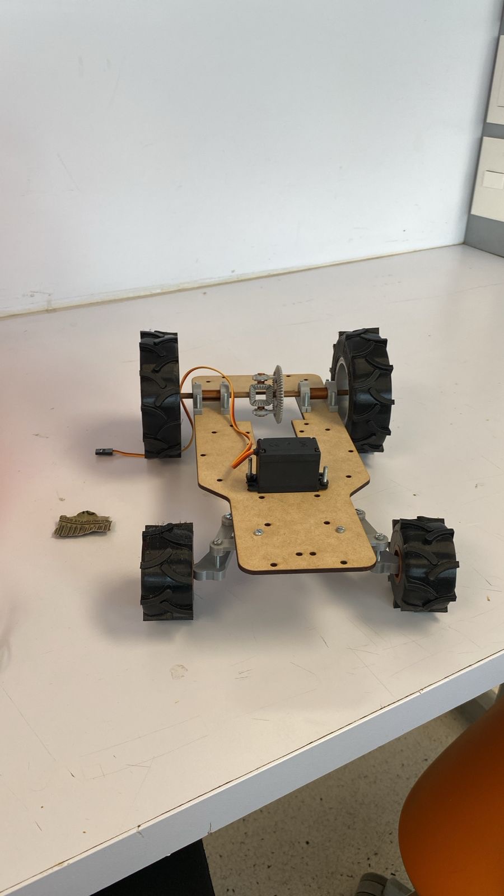
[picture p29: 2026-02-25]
docs/04-media/01-development/mechanical-prototype/attempt-02/car_first_floor_03.JPG

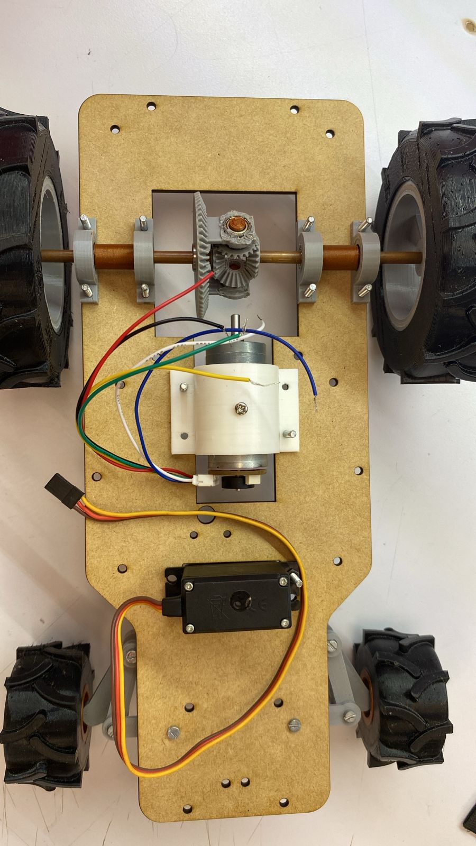
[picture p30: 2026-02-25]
docs/04-media/01-development/mechanical-prototype/attempt-02/car_first_floor_02.JPG

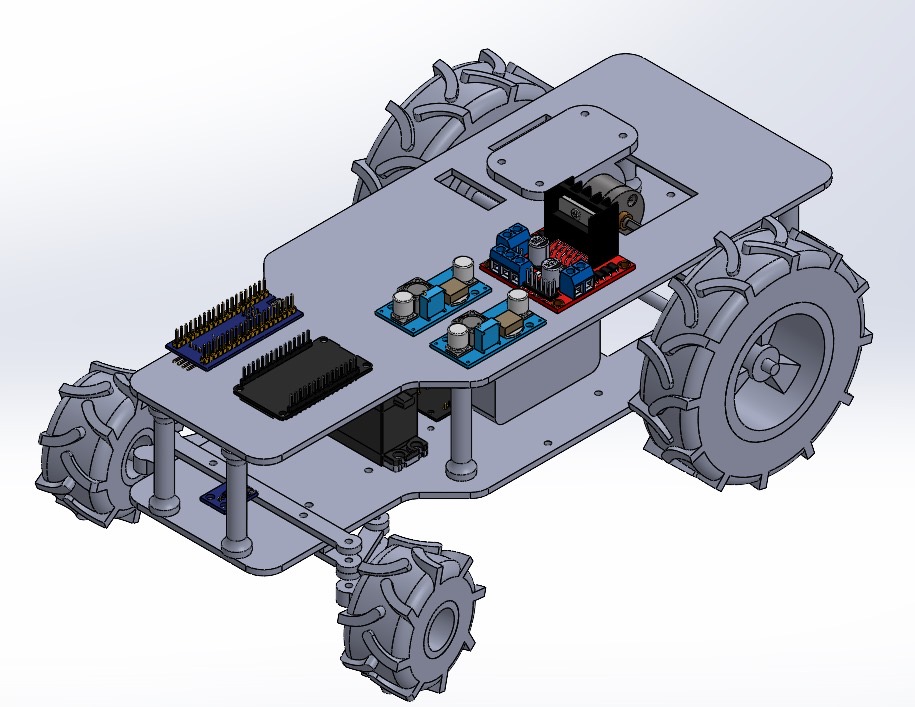
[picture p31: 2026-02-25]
docs/04-media/01-development/mechanical-prototype/attempt-03/cad_second_floor_04.JPG

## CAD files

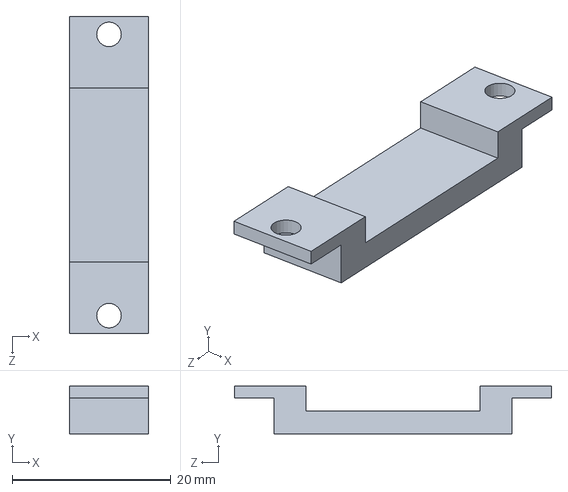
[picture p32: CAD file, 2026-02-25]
hardware/parts/Soporte Ackerman.SLDPRT
10.0 x 6.00 x 40.0 mm

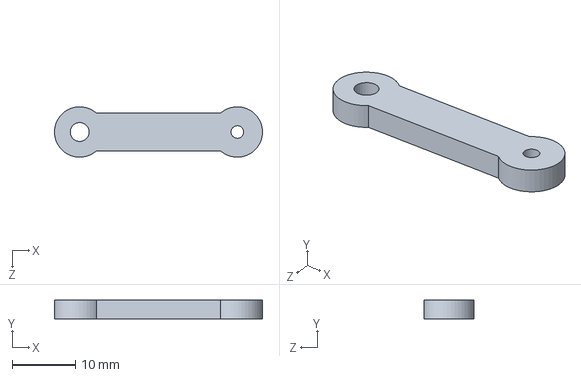
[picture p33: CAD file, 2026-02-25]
hardware/parts/BielaP.SLDPRT
33.0 x 3.00 x 8.00 mm

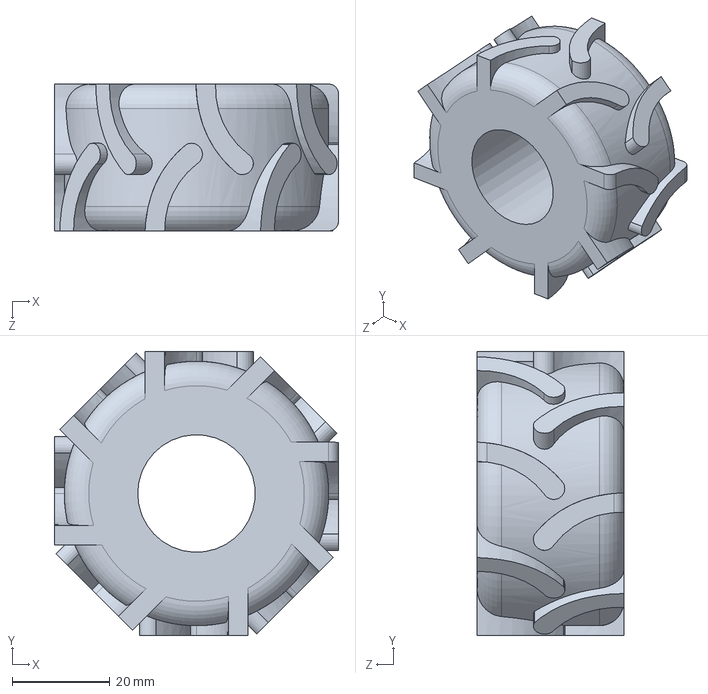
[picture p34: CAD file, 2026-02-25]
hardware/parts/Llanta Ch.SLDPRT
58.0 x 58.0 x 30.0 mm

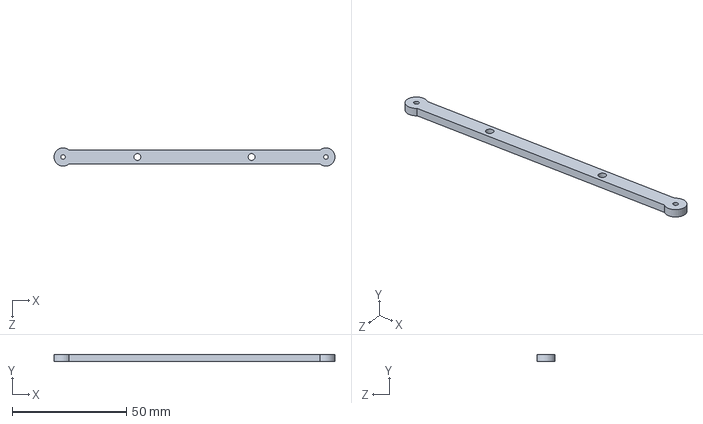
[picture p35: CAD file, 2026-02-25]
hardware/parts/BielaA.SLDPRT
123.0 x 3.00 x 7.98 mm

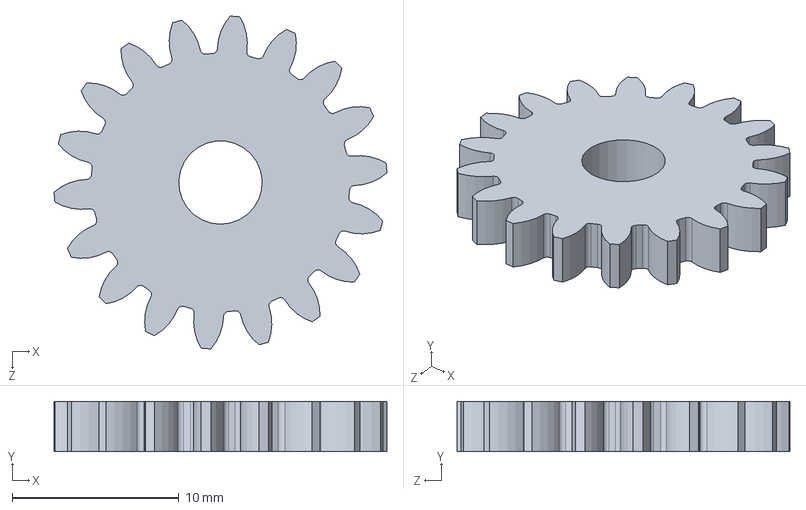
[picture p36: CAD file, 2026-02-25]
hardware/parts/Engrane.SLDPRT
20.0 x 3.00 x 20.0 mm

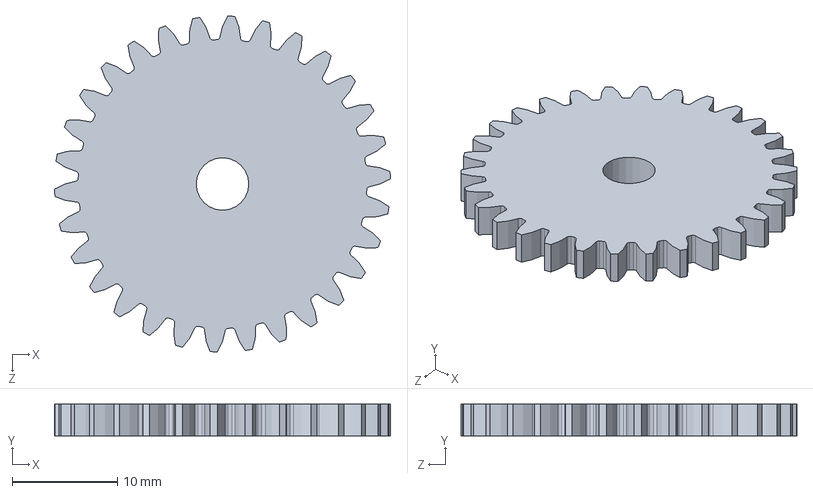
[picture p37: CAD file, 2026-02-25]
hardware/parts/Engrane2.SLDPRT
32.0 x 3.00 x 32.0 mm

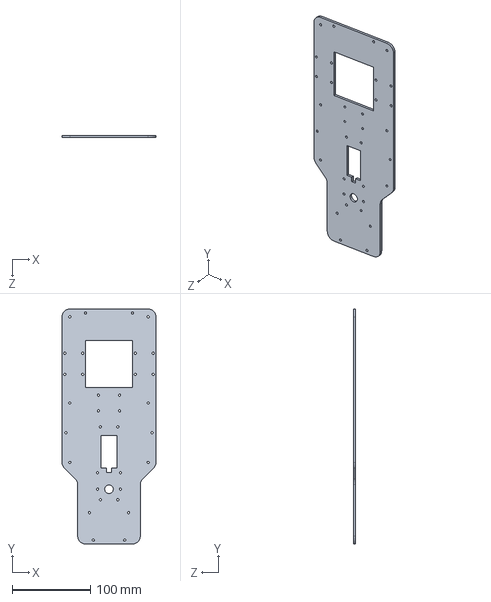
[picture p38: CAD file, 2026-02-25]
hardware/parts/Chasis Reto.SLDPRT
120.0 x 300.0 x 3.00 mm

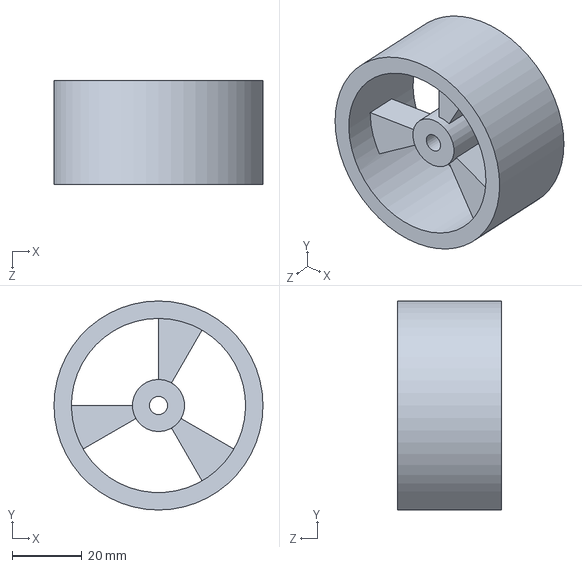
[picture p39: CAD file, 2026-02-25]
hardware/parts/Rin Gde.SLDPRT
60.0 x 60.0 x 30.0 mm

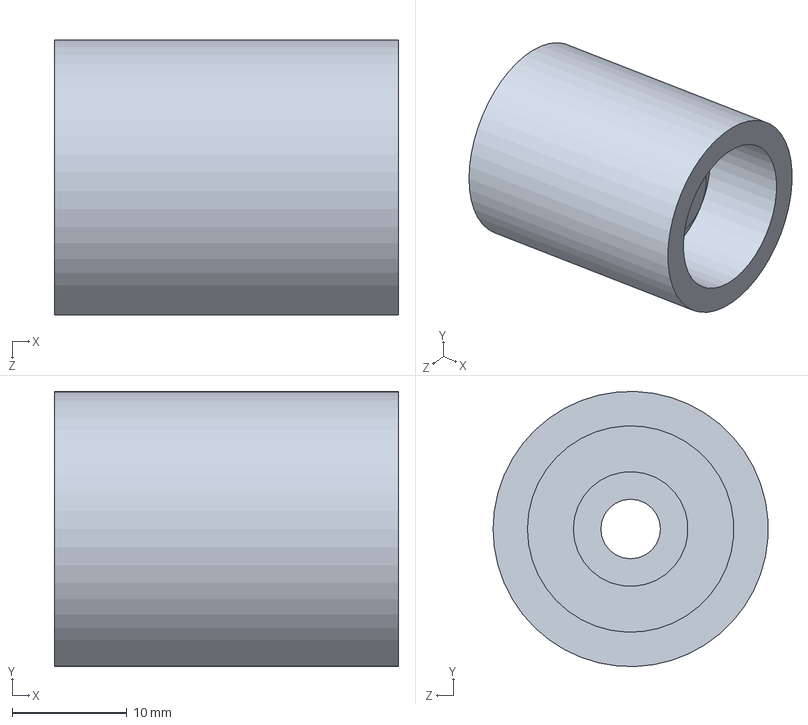
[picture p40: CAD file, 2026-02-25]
hardware/parts/Rin Ch.SLDPRT
30.0 x 24.0 x 24.0 mm

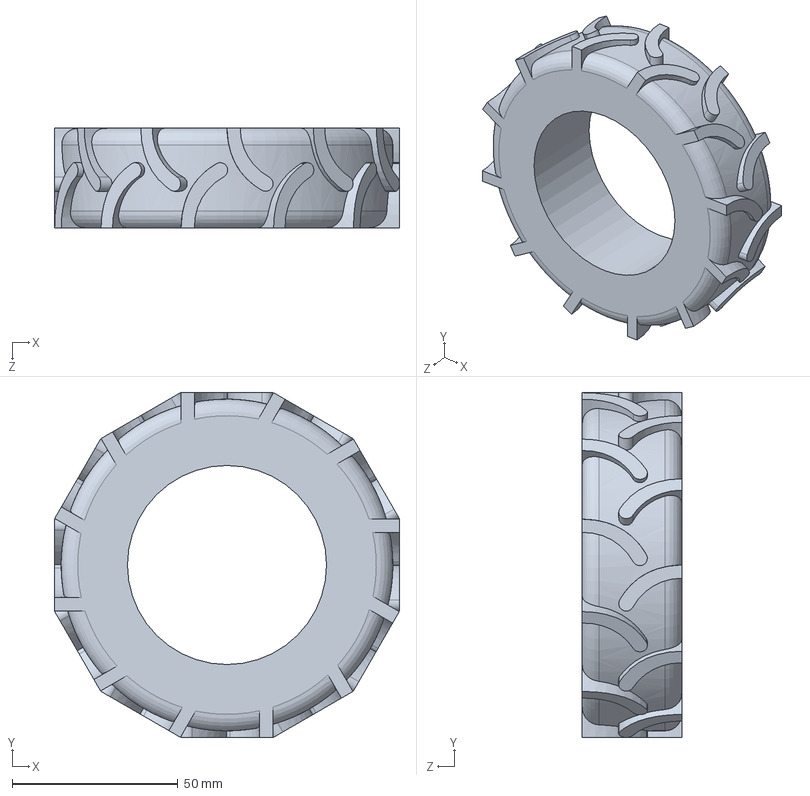
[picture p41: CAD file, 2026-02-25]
hardware/parts/Llanta Gde.SLDPRT
104.0 x 104.0 x 30.0 mm

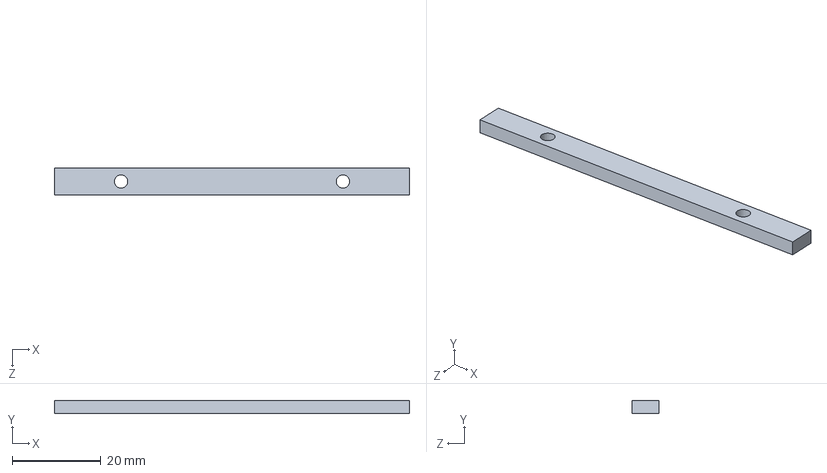
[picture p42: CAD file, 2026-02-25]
hardware/parts/BielaInf.SLDPRT
80.0 x 3.00 x 6.00 mm

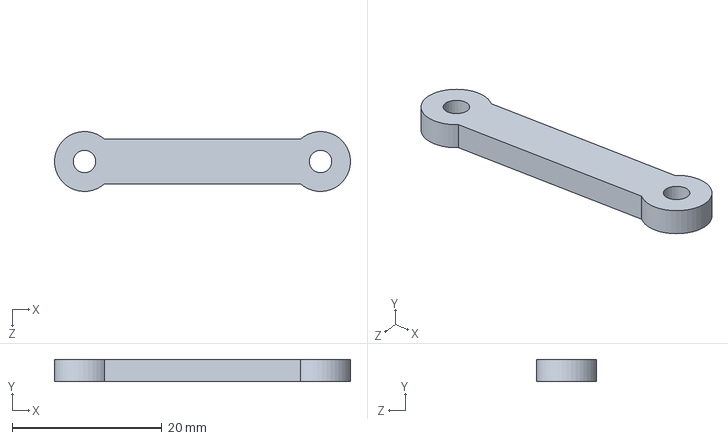
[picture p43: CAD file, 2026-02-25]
hardware/parts/BielaS.SLDPRT
39.5 x 3.00 x 7.99 mm

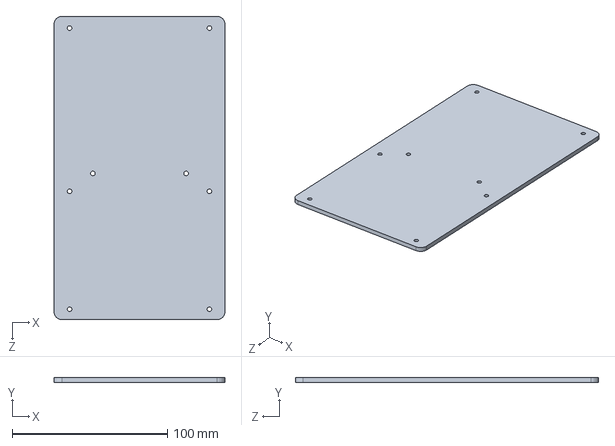
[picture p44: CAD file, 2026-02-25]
hardware/parts/Pisodos.SLDPRT
110.0 x 3.00 x 195.0 mm

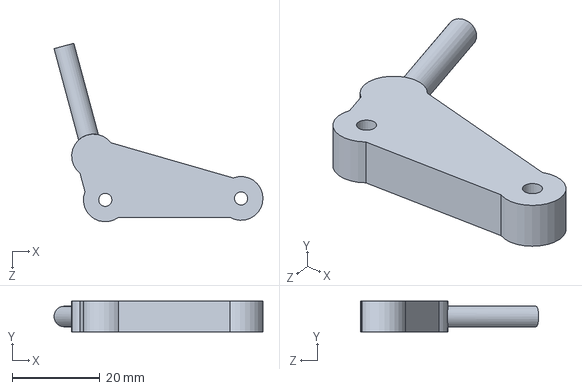
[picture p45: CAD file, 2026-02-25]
hardware/parts/TripodeJ.SLDPRT
47.7 x 7.00 x 40.7 mm

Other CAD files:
hardware/parts/BielaM.SLDPRT
hardware/parts/chumaseras.SLDPRT
hardware/parts/SoporteAckerman.SLDPRT

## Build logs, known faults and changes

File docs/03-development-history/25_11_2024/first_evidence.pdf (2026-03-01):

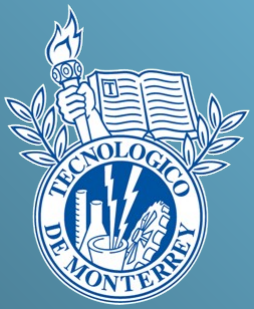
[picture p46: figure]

# 1° Avance de entrega del Reto

# Automatización Industrial

Benjamín Rodríguez Limón – A01741333 Carlos Cuadras Santaella – A01742709 Diego Alejandro Valadez Aramburo – A01710483
Dilan Gerardo Mancilla Cruz – A00837515

06/09/2024

## Propuesta de control:

## Se decidió controlar la dirección del direccional Ackermann con un

servomotor. Y la potencia con un motor DC.

## - Servomotor MG995 - DC 12V DIY Encoder Motorreductor Con Soporte de Montaje

## Como se controlará:

## Con un encoder para posición y velocidad, un ultrasónico para evitar obstáculos y GPS para orientación. Se controlará utilizando un

microcontrolador stm32f1.

## - Stm32f1 - DC 12V DIY Encoder Motorreductor Con Soporte de Montaje - Sensor De Proximidad Capacitivo - WWZMDi ejes Brújula Magnetómetro Sensor Módulo 3.3V

5V

## Módulo de comunicación seleccionado:

## La comunicación se realizará mediante un módulo de bluetooth para

crear la HMI.

## - HC-05 Módulo Bluetooth

## Propuesta de datos a transmitir:

Se desea transmitir velocidad y posición.

## Foto del carrito:

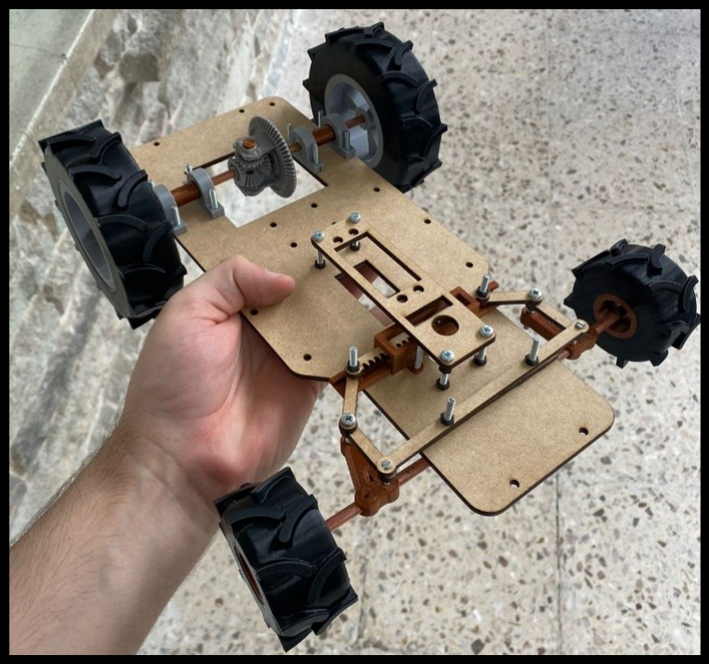
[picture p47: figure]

## Piezas del carrito (Chasis y diferencial):

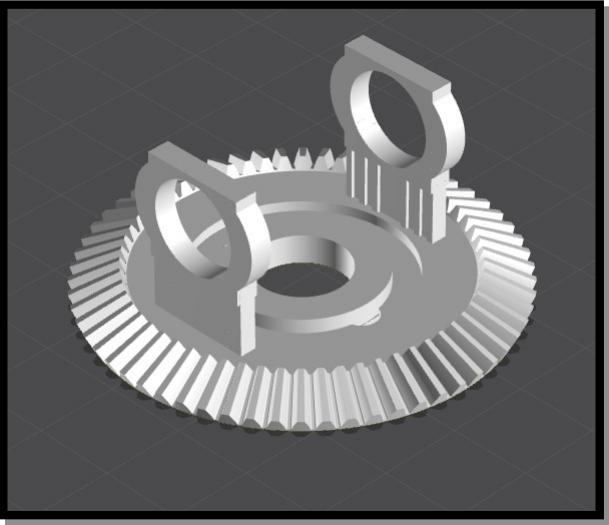
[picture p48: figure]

Ilustración 1 Engrane de corona del diferencial

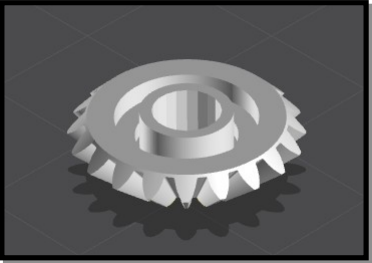
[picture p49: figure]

Ilustración 2 Engrane satélite y planetario del diferencial

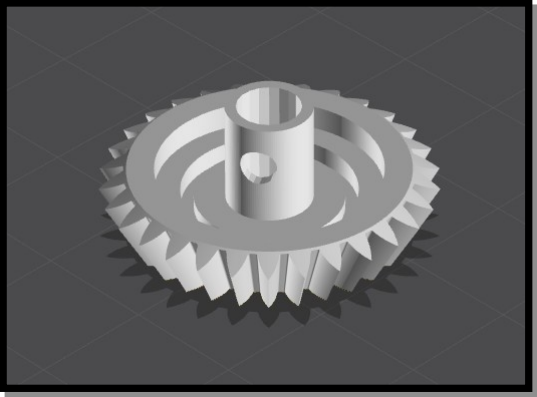
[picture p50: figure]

Ilustración 3 Piñón del diferencial

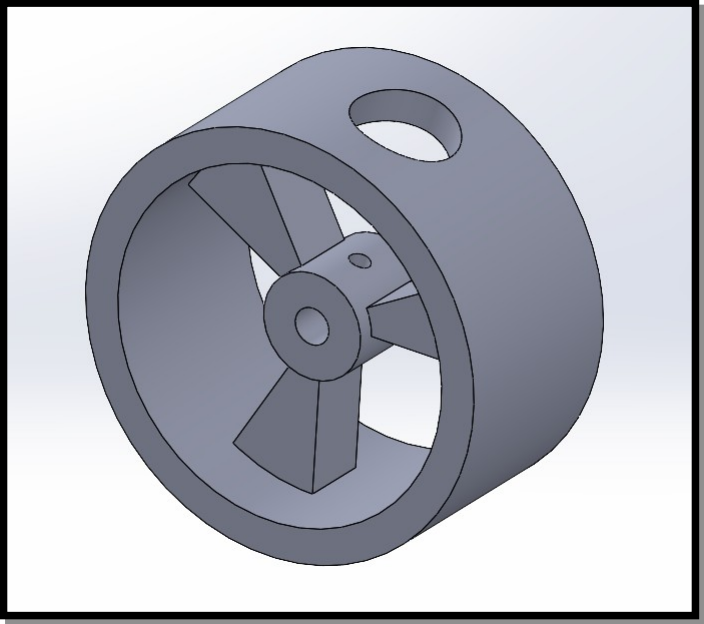
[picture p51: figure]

Ilustración 4 Rin de las llantas traseras

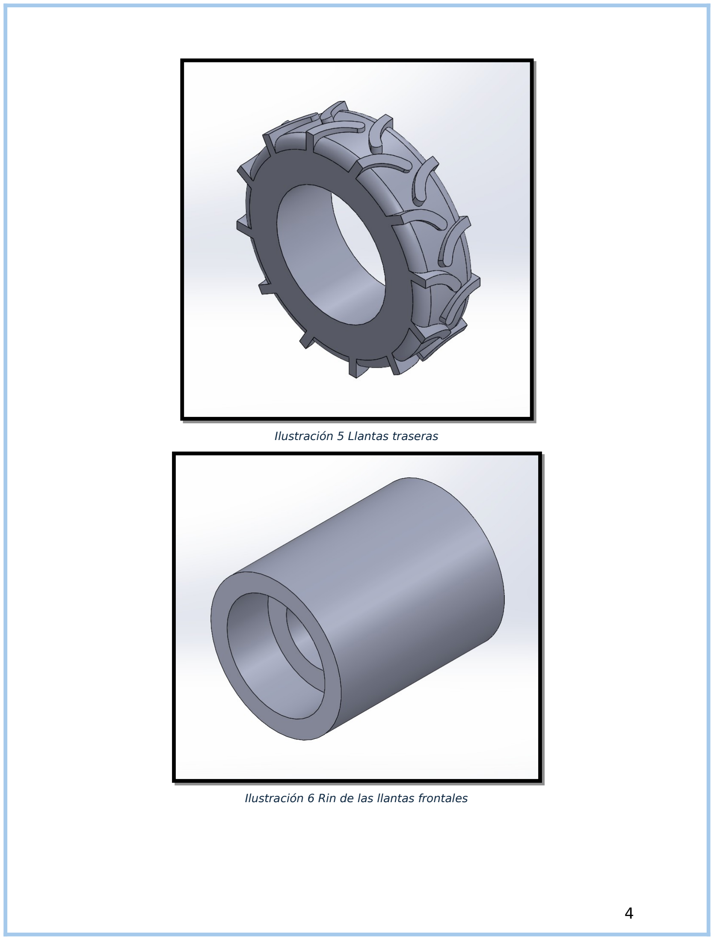
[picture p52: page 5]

Ilustración 5 Llantas traseras

Ilustración 6 Rin de las llantas frontales

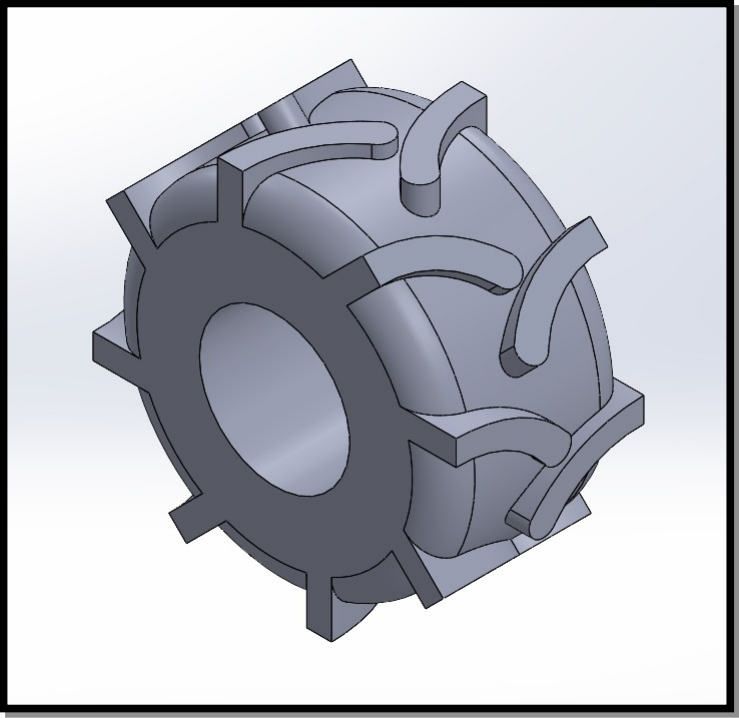
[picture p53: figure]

Ilustración 7 Llantas frontales

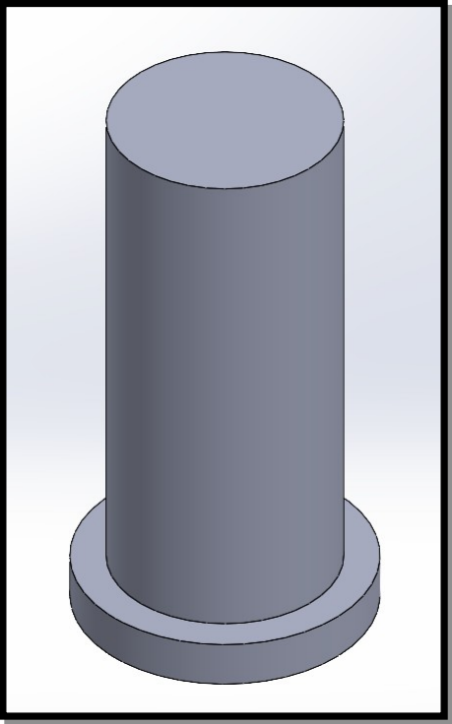
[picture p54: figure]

Ilustración 8 Eje de los engranes planetarios y satélites

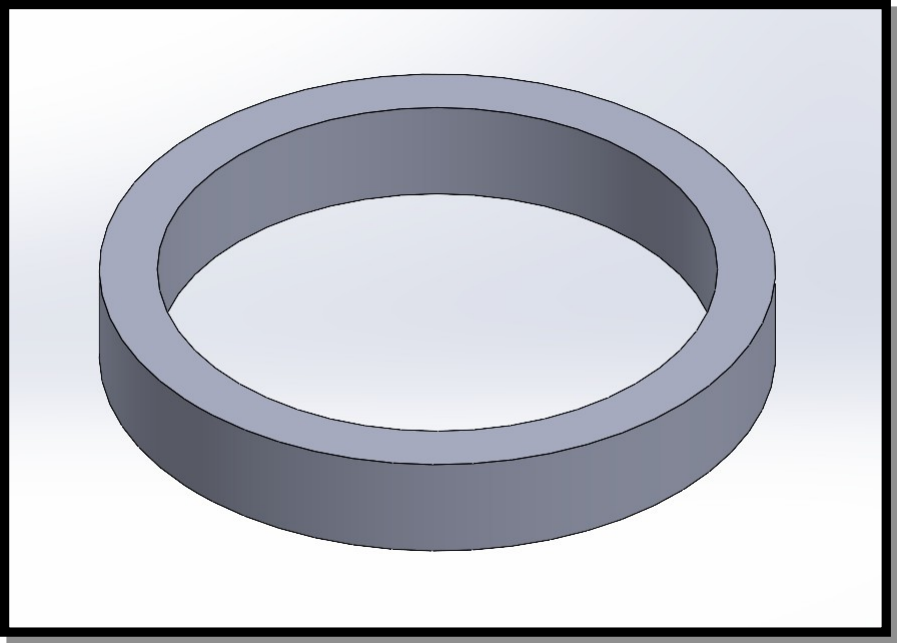
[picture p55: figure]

Ilustración 9 Espaciador de los engranes planetarios y satélites

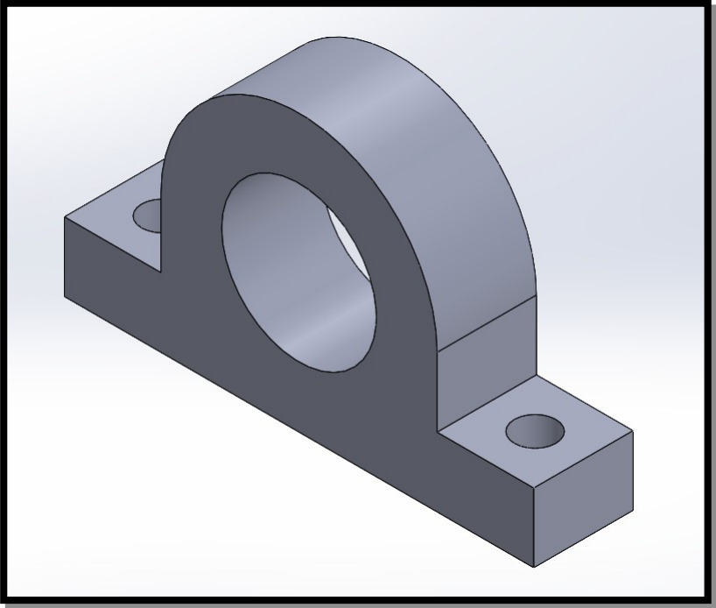
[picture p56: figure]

Ilustración 10 Chumaceras para fijar ejes

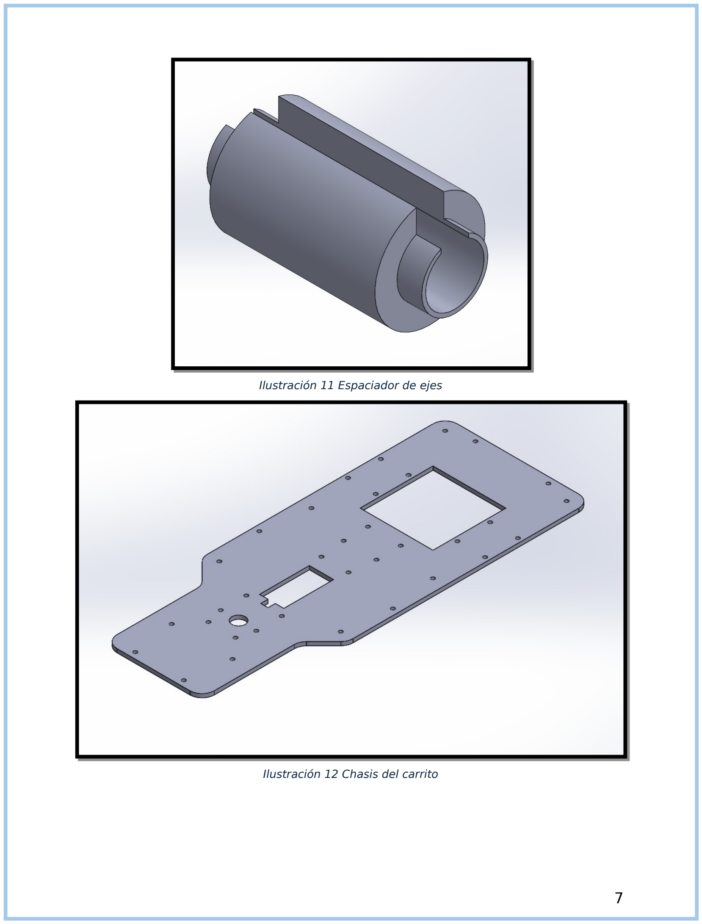
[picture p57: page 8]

Ilustración 11 Espaciador de ejes

Ilustración 12 Chasis del carrito

## Piezas del carrito (Direccional Ackermann):

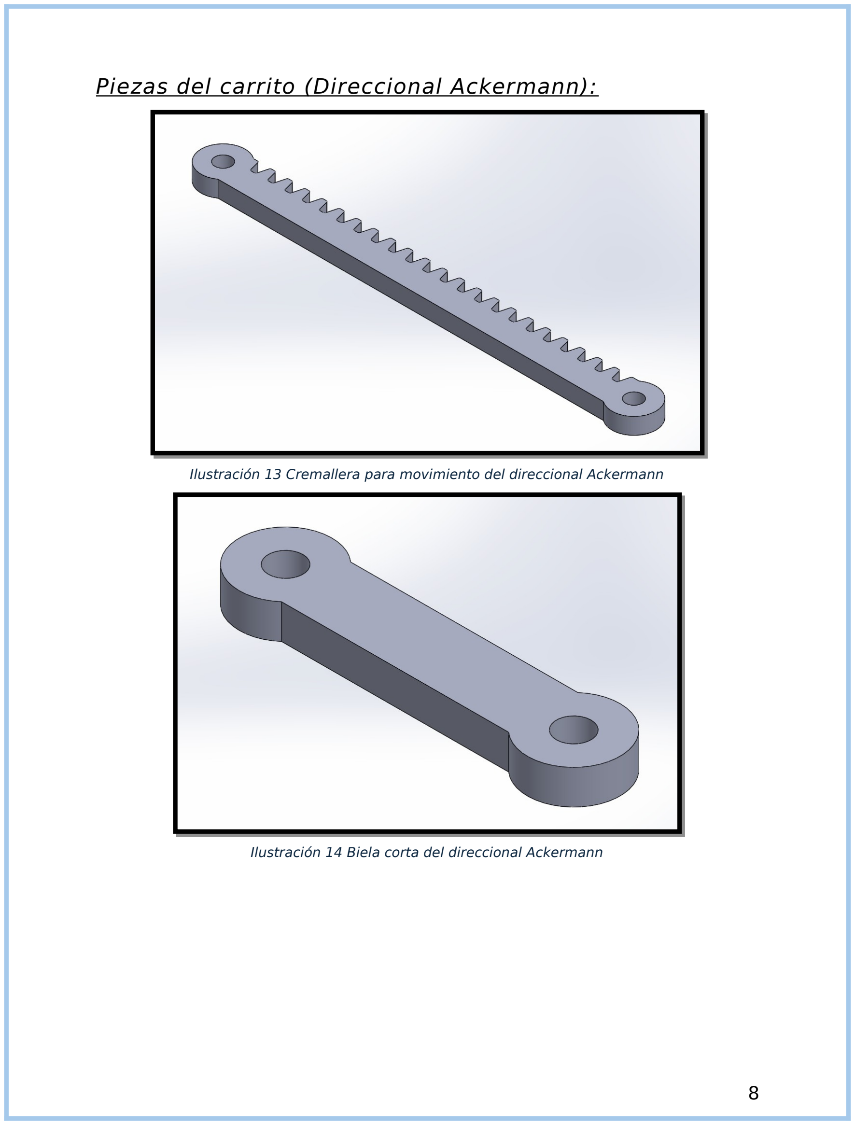
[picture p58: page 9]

Ilustración 13 Cremallera para movimiento del direccional Ackermann

Ilustración 14 Biela corta del direccional Ackermann

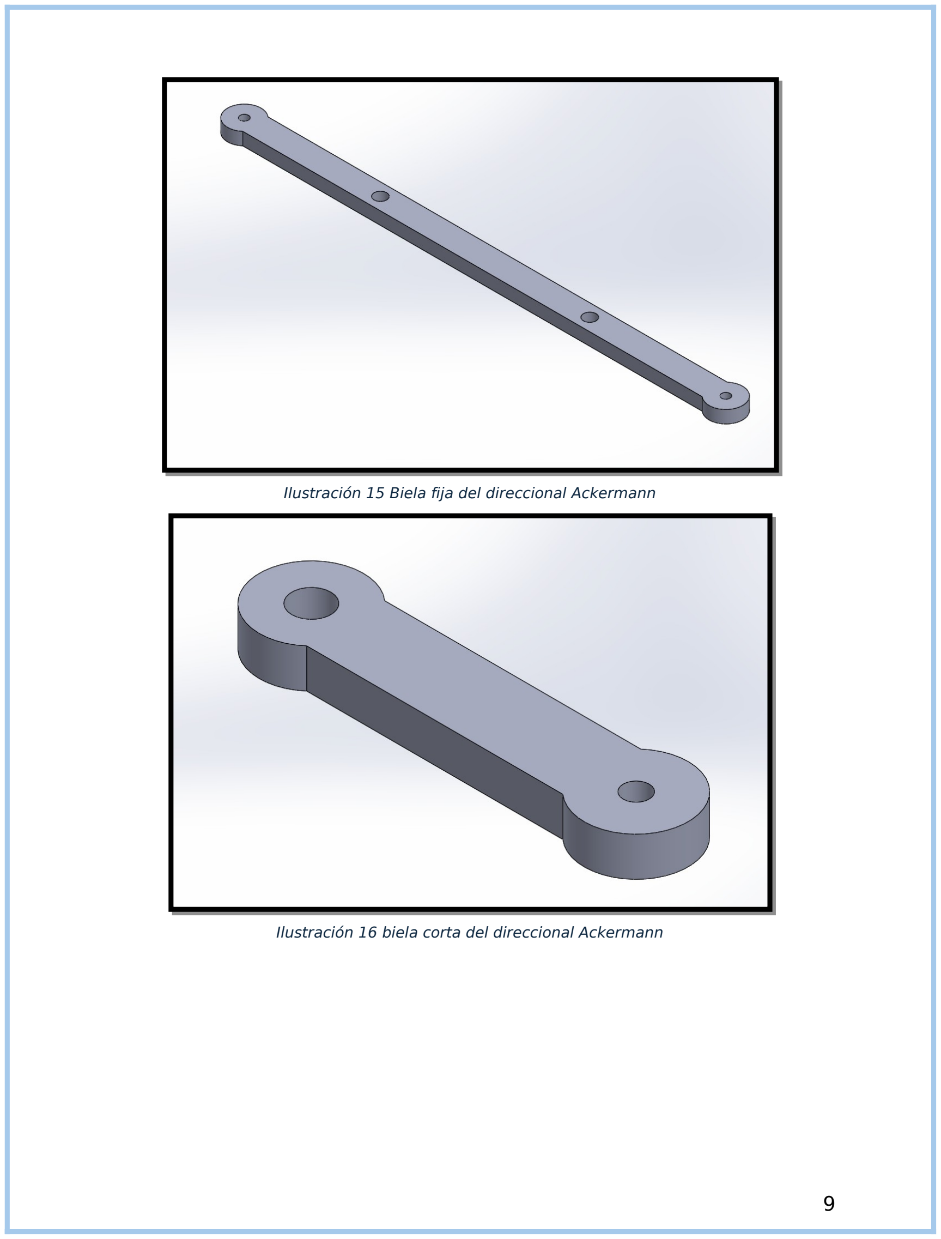
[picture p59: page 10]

Ilustración 15 Biela fija del direccional Ackermann

Ilustración 16 biela corta del direccional Ackermann

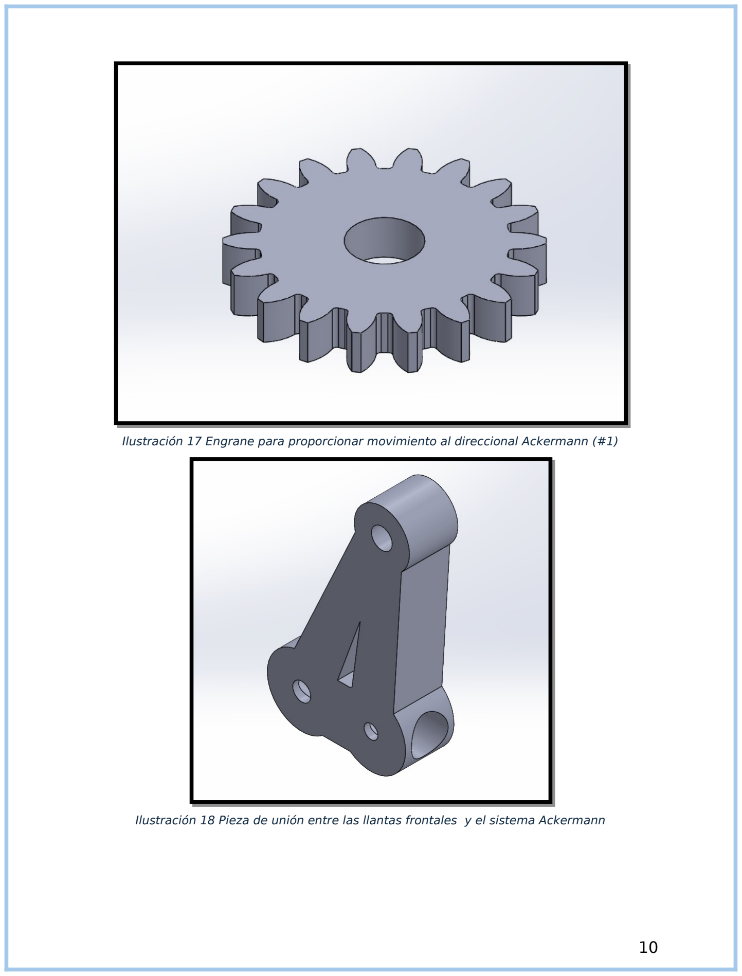
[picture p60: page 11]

Ilustración 17 Engrane para proporcionar movimiento al direccional Ackermann (#1)

Ilustración 18 Pieza de unión entre las llantas frontales y el sistema Ackermann

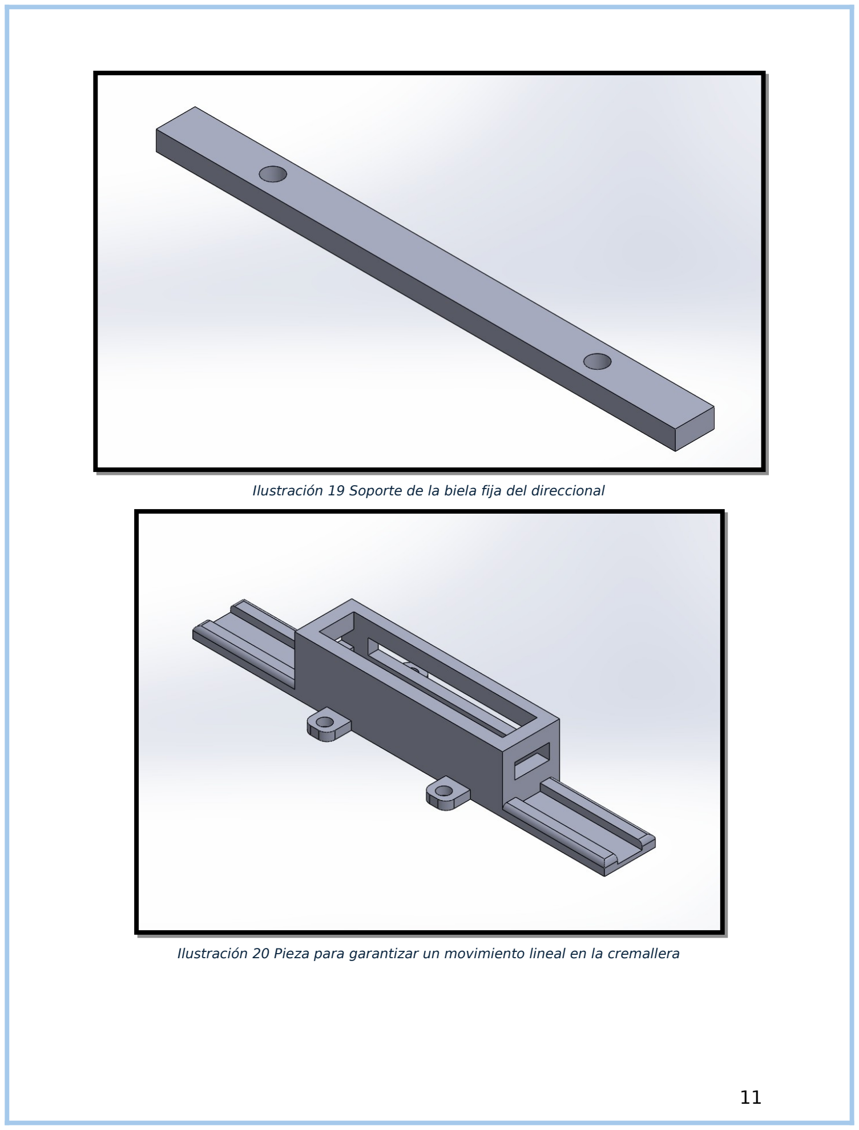
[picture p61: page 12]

Ilustración 19 Soporte de la biela fija del direccional

Ilustración 20 Pieza para garantizar un movimiento lineal en la cremallera

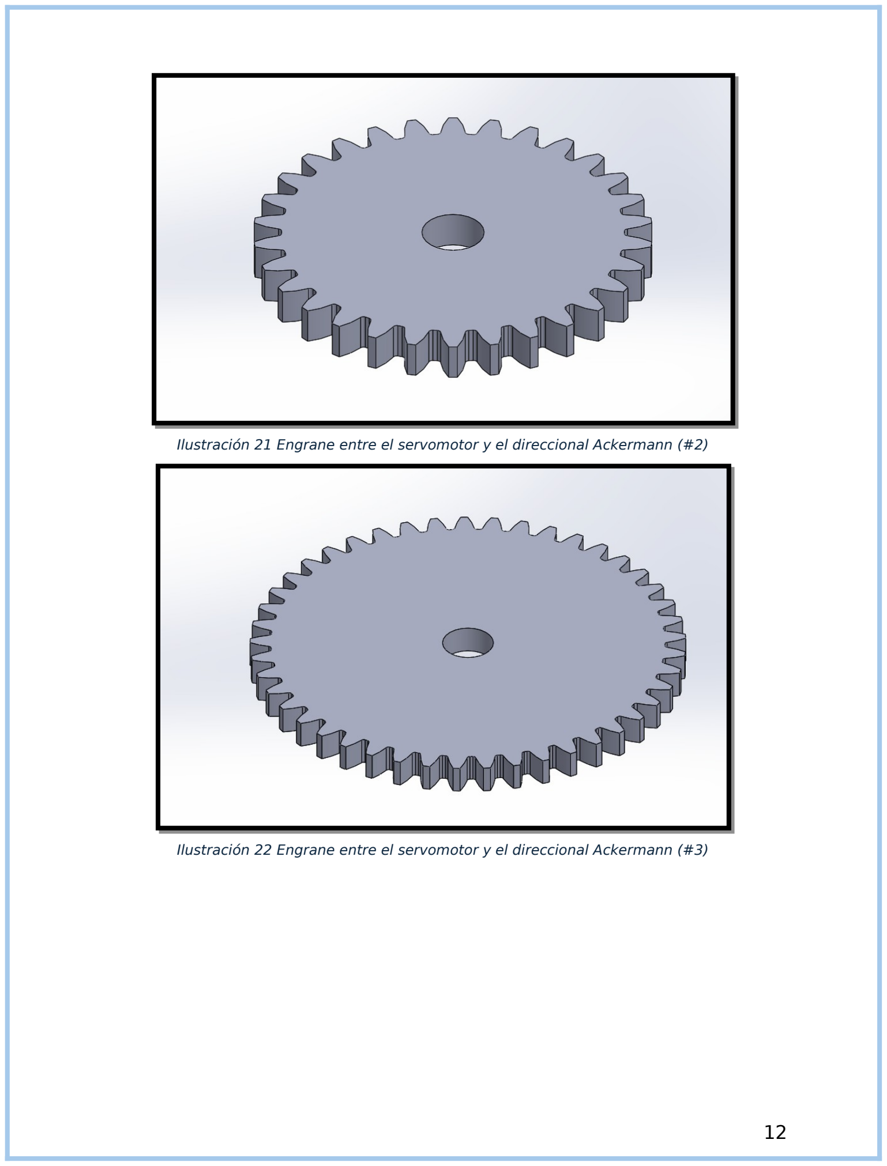
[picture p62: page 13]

Ilustración 21 Engrane entre el servomotor y el direccional Ackermann (#2)

Ilustración 22 Engrane entre el servomotor y el direccional Ackermann (#3)

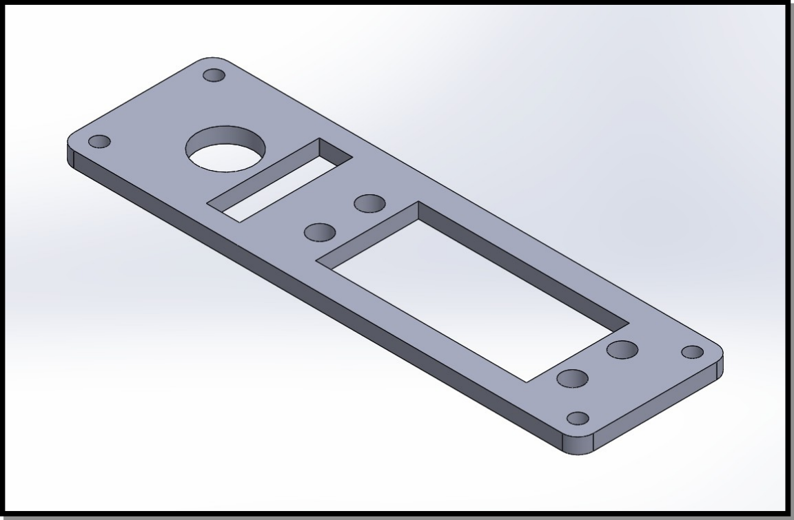
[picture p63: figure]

Ilustración 23 Base para instalar el servomotor

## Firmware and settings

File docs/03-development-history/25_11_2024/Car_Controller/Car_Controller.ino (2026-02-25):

#include <Bluepad32.h>
#include <ESP32Servo.h>
#include <HardwareSerial.h>
#include "UbidotsEsp32Mqtt.h"
#include <WiFi.h>

ControllerPtr myControllers[BP32_MAX_GAMEPADS];

// Pines del ESP32
const int ServoBB = 12;
const int trigPin = 14;
const int echoPin = 27;
const int Forward = 26;
const int Backward = 25;
const int PWM = 33;
#define RXD2 16   // TX (A2) STM32 
#define TXD2 17   // RX (A3) STM32

// Valores Enteros 
int val = 0;
int i = 0;
int i2 = 0;

int brake = 0; 
int throttle;
int estado = 0;
int estadotwo = 0;

// Valores Booleanos
bool autom = false;
bool flagVlc = false;
bool flagSU = false;
bool flagCNE = true;
bool flagPOS = true;
bool flagRUT = false;
bool flagWIFI = false;
bool flagCONB = true;
bool FlagArranqueAuto = false;
bool saltoCorregido = false;
bool flagEspera = false;

// Valores flotantes
long duration;
float desplazamiento = 0;
float distanceCm;
#define SOUND_SPEED 0.034
#define CM_TO_INCH 0.393701

// Arries
float XYZMag[3] = {0.0, 0.0, 0.0};
float Ndis[2] = {};
float Ndeg[2] = {};

// Usa UART2 (pines RX2 = GPIO16, TX2 = GPIO17)
HardwareSerial mySerial(2);
String buffer= "";

// Servomotor
Servo myservo;

// Encoder
const int    C1 = 19; // Entrada de la señal A del encoder.
const int    C2 = 18; // Entrada de la señal B del encoder.

volatile int  n    = 0;
volatile byte ant  = 0;
volatile byte act  = 0;

const float perimetro = 2 * 3.1416 * 0.05; // Reemplaza 'r' por el radio de tu rueda.
const int pasosPorVuelta = 170; // Valor real del encoder.

/* Definimos primero el Token que nos brinda la plataforma Ubidots para hacer la conexión */
const char *UBIDOTS_TOKEN = "BBUS-9UQDRV8xQk2fHnct6vFQN77AuQspzB";
/* Definimos SSID y PASSWORD de nuestra red WiFi */
const char *WIFI_SSID = "Carlos";      
const char *WIFI_PASS = "12345678";     
/* Definimos el nombre de nuestro dispositivo, el cual aparecerá en la plataforma Ubidots */
const char *DEVICE_LABEL = "esp32-conexion";
/* Definimos la variable que se medirá y será publicada en la plataforma Ubidots */
const char *VARIABLE_LABEL_MAG = "esp32-conexion-mag"; 
const char *VARIABLE_LABEL_ENC = "esp32-conexion-enc";
const char *VARIABLE_LABEL_DIS = "esp32-conexion-dis";
/* Definimos la frecuencia de publicación de 5 segundos */
const int PUBLISH_FREQUENCY = 1; 
/* Definimos unas variables extra, que incluye la librería */
unsigned long timer;
uint8_t analogPin = 34; // Pin analógico donde está conectado el potenciómetro
/* Definimos que las variables de la librería UBIDOTS trabajarán con el Token */
Ubidots ubidots(UBIDOTS_TOKEN);

// This callback gets called any time a new gamepad is connected.
// Up to 4 gamepads can be connected at the same time.
void onConnectedController(ControllerPtr ctl) {
    bool foundEmptySlot = false;
    for (int i = 0; i < BP32_MAX_GAMEPADS; i++) {
        if (myControllers[i] == nullptr) {
            Serial.printf("CALLBACK: Controller is connected, index=%d\n", i);
            // Additionally, you can get certain gamepad properties like:
            // Model, VID, PID, BTAddr, flags, etc.
            ControllerProperties properties = ctl->getProperties();
            Serial.printf("Controller model: %s, VID=0x%04x, PID=0x%04x\n", ctl->getModelName().c_str(), properties.vendor_id,
                           properties.product_id);
            myControllers[i] = ctl;
            foundEmptySlot = true;
            break;
        }
    }
    if (!foundEmptySlot) {
        Serial.println("CALLBACK: Controller connected, but could not found empty slot");
    }
}

void onDisconnectedController(ControllerPtr ctl) {
    bool foundController = false;

    for (int i = 0; i < BP32_MAX_GAMEPADS; i++) {
        if (myControllers[i] == ctl) {
            Serial.printf("CALLBACK: Controller disconnected from index=%d\n", i);
            myControllers[i] = nullptr;
            foundController = true;
            break;
        }
    }

    if (!foundController) {
        Serial.println("CALLBACK: Controller disconnected, but not found in myControllers");
    }
}

void dumpGamepad(ControllerPtr ctl) {
    Serial.printf(
        "idx=%d, dpad: 0x%02x, buttons: 0x%04x, axis L: %4d, %4d, axis R: %4d, %4d, brake: %4d, throttle: %4d, "
        "misc: 0x%02x, gyro x:%6d y:%6d z:%6d, accel x:%6d y:%6d z:%6d\n",
        ctl->index(),        // Controller Index
        ctl->dpad(),         // D-pad
        ctl->buttons(),      // bitmask of pressed buttons
        ctl->axisX(),        // (-511 - 512) left X Axis
        ctl->axisY(),        // (-511 - 512) left Y axis
        ctl->axisRX(),       // (-511 - 512) right X axis
        ctl->axisRY(),       // (-511 - 512) right Y axis
        ctl->brake(),        // (0 - 1023): brake button
        ctl->throttle(),     // (0 - 1023): throttle (AKA gas) button
        ctl->miscButtons(),  // bitmask of pressed "misc" buttons
        ctl->gyroX(),        // Gyro X
        ctl->gyroY(),        // Gyro Y
        ctl->gyroZ(),        // Gyro Z
        ctl->accelX(),       // Accelerometer X
        ctl->accelY(),       // Accelerometer Y
        ctl->accelZ()        // Accelerometer Z
    );
}

void dumpMouse(ControllerPtr ctl) {
    Serial.printf("idx=%d, buttons: 0x%04x, scrollWheel=0x%04x, delta X: %4d, delta Y: %4d\n",
                   ctl->index(),        // Controller Index
                   ctl->buttons(),      // bitmask of pressed buttons
                   ctl->scrollWheel(),  // Scroll Wheel
                   ctl->deltaX(),       // (-511 - 512) left X Axis
                   ctl->deltaY()        // (-511 - 512) left Y axis
    );
}

void dumpKeyboard(ControllerPtr ctl) {
    static const char* key_names[] = {
        // clang-format off
        // To avoid having too much noise in this file, only a few keys are mapped to strings.
        // Starts with "A", which is offset 4.
        "A", "B", "C", "D", "E", "F", "G", "H", "I", "J", "K", "L", "M", "N", "O", "P", "Q", "R", "S", "T", "U", "V",
        "W", "X", "Y", "Z", "1", "2", "3", "4", "5", "6", "7", "8", "9", "0",
        // Special keys
        "Enter", "Escape", "Backspace", "Tab", "Spacebar", "Underscore", "Equal", "OpenBracket", "CloseBracket",
        "Backslash", "Tilde", "SemiColon", "Quote", "GraveAccent", "Comma", "Dot", "Slash", "CapsLock",
        // Function keys
        "F1", "F2", "F3", "F4", "F5", "F6", "F7", "F8", "F9", "F10", "F11", "F12",
        // Cursors and others
        "PrintScreen", "ScrollLock", "Pause", "Insert", "Home", "PageUp", "Delete", "End", "PageDown",
        "RightArrow", "LeftArrow", "DownArrow", "UpArrow",
        // clang-format on
    };
    static const char* modifier_names[] = {
        // clang-format off
        // From 0xe0 to 0xe7
        "Left Control", "Left Shift", "Left Alt", "Left Meta",
        "Right Control", "Right Shift", "Right Alt", "Right Meta",
        // clang-format on
    };
    Serial.printf("idx=%d, Pressed keys: ", ctl->index());
    for (int key = Keyboard_A; key <= Keyboard_UpArrow; key++) {
        if (ctl->isKeyPressed(static_cast<KeyboardKey>(key))) {
            const char* keyName = key_names[key-4];
            Serial.printf("%s,", keyName);
       }
    }
    for (int key = Keyboard_LeftControl; key <= Keyboard_RightMeta; key++) {
        if (ctl->isKeyPressed(static_cast<KeyboardKey>(key))) {
            const char* keyName = modifier_names[key-0xe0];
            Serial.printf("%s,", keyName);
        }
    }
    Console.printf("\n");
}

void dumpBalanceBoard(ControllerPtr ctl) {
    Serial.printf("idx=%d,  TL=%u, TR=%u, BL=%u, BR=%u, temperature=%d\n",
                   ctl->index(),        // Controller Index
                   ctl->topLeft(),      // top-left scale
                   ctl->topRight(),     // top-right scale
                   ctl->bottomLeft(),   // bottom-left scale
                   ctl->bottomRight(),  // bottom-right scale
                   ctl->temperature()   // temperature: used to adjust the scale value's precision
    );
}

void processGamepad(ControllerPtr ctl) {
    
    // Medicion de Variables
    val = map(ctl->axisX(),512,-511, 33, 132);
    throttle = map(ctl->throttle(), 0, 1023, 0, 255);
    brake = map(ctl->brake(), 0, 1023, 0, 255);

    // Declaración de estados
    
    if (ctl->b()) {
        autom = !autom;
        if (autom == true){
          Serial.println("Automatico");
          delay(250);
        }
        if (autom == false){
          Serial.println("Control");
          delay(250);
        }
    }

    if (ctl->a()) {
        FlagArranqueAuto = !FlagArranqueAuto;
        if (FlagArranqueAuto == true){
          Serial.println("ArranqueAutoOn");
          delay(250);
        }
        if (FlagArranqueAuto == false){
          Serial.println("FlagArranqueAutoOff");
          delay(250);
        }
    }

    if (ctl->x()) {
        flagWIFI = !flagWIFI;
        if (flagWIFI == true){
          Serial.println("DatosON");
          delay(250);
        }
        if (flagWIFI == false){
          Serial.println("DatosOFF");
          delay(250);
        }
    }
}

void processMouse(ControllerPtr ctl) {
    // This is just an example.
    if (ctl->scrollWheel() > 0) {
        // Do Something
    } else if (ctl->scrollWheel() < 0) {
        // Do something else
    }

    // See "dumpMouse" for possible things to query.
    dumpMouse(ctl);
}

void processKeyboard(ControllerPtr ctl) {
    if (!ctl->isAnyKeyPressed())
        return;

    // This is just an example.
    if (ctl->isKeyPressed(Keyboard_A)) {
        // Do Something
        Serial.println("Key 'A' pressed");
    }

    // Don't do "else" here.
    // Multiple keys can be pressed at the same time.
    if (ctl->isKeyPressed(Keyboard_LeftShift)) {
        // Do something else
        Serial.println("Key 'LEFT SHIFT' pressed");
    }

    // Don't do "else" here.
    // Multiple keys can be pressed at the same time.
    if (ctl->isKeyPressed(Keyboard_LeftArrow)) {
        // Do something else
        Serial.println("Key 'Left Arrow' pressed");
    }

    // See "dumpKeyboard" for possible things to query.
    dumpKeyboard(ctl);
}

void processBalanceBoard(ControllerPtr ctl) {
    // This is just an example.
    if (ctl->topLeft() > 10000) {
        // Do Something
    }

    // See "dumpBalanceBoard" for possible things to query.
    dumpBalanceBoard(ctl);
}

void processControllers() {
    for (auto myController : myControllers) {
        if (myController && myController->isConnected() && myController->hasData()) {
            if (myController->isGamepad()) {
                processGamepad(myController);
            } else if (myController->isMouse()) {
                processMouse(myController);
            } else if (myController->isKeyboard()) {
                processKeyboard(myController);
            } else if (myController->isBalanceBoard()) {
                processBalanceBoard(myController);
            } else {
                Serial.println("Unsupported controller");
            }
        }
    }
}

// Arduino setup function. Runs in CPU 1
void setup() {
    Serial.begin(115200);
    Serial.printf("Firmware: %s\n", BP32.firmwareVersion());
    const uint8_t* addr = BP32.localBdAddress();
    Serial.printf("BD Addr: %2X:%2X:%2X:%2X:%2X:%2X\n", addr[0], addr[1], addr[2], addr[3], addr[4], addr[5]);

    // Setup the Bluepad32 callbacks
    BP32.setup(&onConnectedController, &onDisconnectedController);

    // "forgetBluetoothKeys()" should be called when the user performs
    // a "device factory reset", or similar.
    // Calling "forgetBluetoothKeys" in setup() just as an example.
    // Forgetting Bluetooth keys prevents "paired" gamepads to reconnect.
    // But it might also fix some connection / re-connection issues.
    BP32.forgetBluetoothKeys();

    // Enables mouse / touchpad support for gamepads that support them.
    // When enabled, controllers like DualSense and DualShock4 generate two connected devices:
    // - First one: the gamepad
    // - Second one, which is a "virtual device", is a mouse.
    // By default, it is disabled.
    BP32.enableVirtualDevice(false);

    /* Ahora, se incluyen las funciones de conexión de la Plataforma, como la conexión a internet con las credenciales de WiFi */
    // ubidots.setDebug(true);  // Descomentar esto para que los mensajes de depuración estén disponibles
    //ubidots.connectToWifi(WIFI_SSID, WIFI_PASS);
    /* Se incluye las funciones de Setup y Reconnect, predefinidas de la librería */
    //ubidots.setup();
    //ubidots.reconnect();
    timer = millis();

    // Declaración de pines
    pinMode(Forward,OUTPUT);
    pinMode(Backward,OUTPUT);
    pinMode(trigPin, OUTPUT); // Sets the trigPin as an Output
    pinMode(echoPin, INPUT); // Sets the echoPin as an Input
    ledcAttachPin(PWM, 2);
    ledcSetup(2,8000,8);
    
    // Declaración del servomotor
    myservo.attach(ServoBB);

    // Encoder
    attachInterrupt(digitalPinToInterrupt(C1), encoder, CHANGE);
    attachInterrupt(digitalPinToInterrupt(C2), encoder, CHANGE);
    
    // Comunicación UART
    mySerial.begin(115200, SERIAL_8N1, RXD2, TXD2);

}

// Arduino loop function. Runs in CPU 1.
void loop() {
  // This call fetches all the controllers' data.
  // Call this function in your main loop.
  bool dataUpdated = BP32.update();
  if (dataUpdated)
      processControllers();

  // The main loop must have some kind of "yield to lower priority task" event.
  // Otherwise, the watchdog will get triggered.
  // If your main loop doesn't have one, just add a simple `vTaskDelay(1)`.
  // Detailed info here:
  // https://stackoverflow.com/questions/66278271/task-watchdog-got-triggered-the-tasks-did-not-reset-the-watchdog-in-time

  // vTaskDelay(1);

  /* Definimos que, si no se conecta a la plataforma Ubidots, se pasa la función Reconnect() para volver a establecer la conexión */
  if (flagWIFI == true){
    if (flagCONB == true){
      Serial.println("Conectado");
      flagCONB = false;
      ubidots.connectToWifi(WIFI_SSID, WIFI_PASS);
      ubidots.setup();
      if (!ubidots.connected()) {
        ubidots.reconnect();
      }
    }
  } else {
    if (flagCONB == false){
      Serial.println("Desconectado");
      flagCONB = true;
      WiFi.disconnect();
    }
  }
  if (autom == true){
    Automatico();
  }

  if (autom == false){
    Control();
  }

  delay(1); 
  ubidots.loop();
}

void Control(){
  // Reinicio de variables
  flagSU = false;
  flagCNE = true;
  flagPOS = true;
  flagRUT = false;
  flagEspera = false;
  estado = 0;
  estadotwo = 0;
  i = 0;
  i2 = 0;

  encoder();
  desplazamiento = (float(n) / pasosPorVuelta) * perimetro;
  Serial.print("desplazamiento :");
  Serial.print(desplazamiento);

  Serial.print(", n :");
  Serial.println(n);
  
  if(WiFi.status() == WL_CONNECTED){
    Sending();
  }
  
  myservo.write(val);
  
  if (throttle > 0  && brake > 0){
    flagVlc = true;
    ledcWrite(2, throttle);
  }
  if (throttle > 0  != brake > 0){
    flagVlc = false;
    ledcWrite(2, brake);
  }
  if (brake == 0 || flagVlc == true){ 
    digitalWrite(Backward,LOW);
    ledcWrite(2, brake);
  }
  if (throttle == 0 || flagVlc == true){
    digitalWrite(Forward,LOW);
    ledcWrite(2, brake);
  }
  if (throttle > 0 && flagVlc == false){
    digitalWrite(Backward,LOW);
    digitalWrite(Forward,HIGH);
    if (throttle > 0 && throttle < 175){
      throttle = 175;
    }
    ledcWrite(2, throttle);
  }
  if (brake > 0 && flagVlc == false){
    digitalWrite(Forward,LOW);
    digitalWrite(Backward,HIGH);
    if (brake > 0 && brake < 175){
      brake = 175;
    }
    ledcWrite(2, brake);
  }
  delay(100);
}

void Automatico(){
  if(WiFi.status() == WL_CONNECTED){
    Sending();
  }

  Ndis[1] = Ndis[0];
  Ndis[0] = Ultrasonic();
  if (Ndis[0] <= 10){
    Ndis[0] = Ndis[1];
  }
  Ndeg[1] = Ndeg[0];
  Ndeg[0] = Magnetometro(XYZMag);
  if (Ndeg[0] == 0){
    Ndeg[0] = Ndeg[1];
  }
  


  if (FlagArranqueAuto == true && flagCNE == true  && flagEspera == false){
    digitalWrite(Forward,HIGH);
    ledcWrite(2, 180);
  } 
    
  if((FlagArranqueAuto != true) || flagEspera == true){
    digitalWrite(Forward,LOW);
    ledcWrite(2, 0);
    estado = 0; 
    i = 0;
    flagSU = false;
    flagCNE = true;
  }

  if (estadotwo == 0){
    Nort();
  }
  if (estadotwo == 1){
    East();
  }
  if (estadotwo == 2){
    South();
  }
  if (estadotwo == 3){
    West();
  } 

  if ((Ndis[0] <= 30 || flagSU == true) && FlagArranqueAuto == true){
    flagSU = true;
    Secuencia();
  }

  if (flagRUT == true  && flagCNE == true){
    Espera();
  }
  Serial.print("Grados: ");
  Serial.print(Ndeg[0]);
  Serial.print(", distancia, ");
  Serial.print(Ndis[0]);
  Serial.print("estadotwo: ");
  Serial.println(estadotwo);
  delay(49);
}

void Espera(){
  i2++;
  Serial.println("Procesando");
  Serial.println(i2);
  if (i2 >= 80){
    flagRUT = false;
    flagPOS = true;
    flagEspera = false;
    estadotwo++;
    i2 = 0;
    Serial.println("Llegada");
  }
  if (estadotwo >= 4){
    estadotwo = 0;
  };
}

void Nort(){
  Serial.println("Norte, ");
  if (((Ndeg[0] >= 0 &&  Ndeg[0] <= 10) ||  (Ndeg[0] <= 360 &&  Ndeg[0] >= 335)) && (flagSU == false)){
    if (flagPOS == true){
      flagPOS = false;
      n = 0;
    }
    myservo.write(88);
    encoder();
    desplazamiento = (float(n) / pasosPorVuelta) * perimetro;
    Serial.println("desplazamiento :");
    Serial.println(desplazamiento);
    
    if (desplazamiento >= 2.5){
      flagRUT = true;
      flagEspera = true;
    }   
  }
  if ((Ndeg[0] > 10 && Ndeg[0] < 180) && ((flagSU == false))){
      myservo.write(115);
  }
  if ((Ndeg[0] >= 180 && Ndeg[0] < 350) && (flagSU == false)){
    myservo.write(45);
  }
}

void East(){
  Serial.println("Este");
  if (((Ndeg[0] >= 75 &&  Ndeg[0] <= 110)) && (flagSU == false)){
    if (flagPOS == true){
      flagPOS = false;
      n = 0;
    }
    myservo.write(88);
    encoder();
    desplazamiento = (float(n) / pasosPorVuelta) * perimetro;
    Serial.println("desplazamiento :");
    Serial.println(desplazamiento);
    if (desplazamiento >= 2.5){
      flagRUT = true;
      flagEspera = true;
    }   
  }
  if (((Ndeg[0] >= 0 &&  Ndeg[0] < 75) ||  (Ndeg[0] <= 360 &&  Ndeg[0] >= 270)) && ((flagSU == false))){
    myservo.write(45);
  }
  if ((Ndeg[0] > 110 && Ndeg[0] < 270) && ((flagSU == false))){
      myservo.write(115);
  }
}

void South(){
  Serial.println("Sur");
  if (((Ndeg[0] >= 170 &&  Ndeg[0] <= 200)) && (flagSU == false)){
    if (flagPOS == true){
      flagPOS = false;
      n = 0;
    }
    myservo.write(88);
    encoder();
    desplazamiento = (float(n) / pasosPorVuelta) * perimetro;
    Serial.println("desplazamiento :");
    Serial.println(desplazamiento);
    if (desplazamiento >= 2.5){
      flagRUT = true;
      flagEspera = true;
    }   
  }
  if ((Ndeg[0] >= 0 &&  Ndeg[0] < 170) && (flagSU == false)){
    myservo.write(45);
  }
  if ((Ndeg[0] > 200 && Ndeg[0] <= 360) && ((flagSU == false))){
      myservo.write(115);
  }
}

void West(){
  Serial.println("Este");
  if (((Ndeg[0] >= 260 &&  Ndeg[0] <= 280)) && (flagSU == false)){
    if (flagPOS == true){
      flagPOS = false;
      n = 0;
    }
    myservo.write(88);
    encoder();
    desplazamiento = (float(n) / pasosPorVuelta) * perimetro;
    Serial.println("desplazamiento :");
    Serial.println(desplazamiento);
    if (desplazamiento >= 2.5){
      flagRUT = true;
      flagEspera = true;
    }   
  }
  if ((Ndeg[0] >= 90 &&  Ndeg[0] < 260) && (flagSU == false)){
    myservo.write(45);
  }
  if (((Ndeg[0] >= 0 &&  Ndeg[0] < 90 ) ||  (Ndeg[0] <= 360 &&  Ndeg[0] > 280)) && ((flagSU == false))){
      myservo.write(115);
  }
}

void Secuencia() {
  switch (estado) {
    case 0: // Encender el LED durante 500 ms
      digitalWrite(Forward,LOW);
      digitalWrite(Backward,LOW);
      myservo.write(88);
      ledcWrite(2, 0);
      i++;
      if (i == 40){
        estado = 1;  
        i = 0;
      }
      if (flagCNE == true){
        flagCNE = false;
      }
      break;
    case 1:
      digitalWrite(Forward,LOW);
      digitalWrite(Backward,HIGH);
      ledcWrite(2, 180);
      i++;
      if (i == 25){
        estado = 2;  
        i = 0;
      }
      break;
    case 2:
      digitalWrite(Forward,LOW);
      digitalWrite(Backward,LOW);
      ledcWrite(2, 0);
      i++;
      if (i == 40){
        estado = 3;  
        i = 0;
      }
      break;
    case 3:
      if (Ndis[0] <= 50){
        estado = 0;
      }
      digitalWrite(Forward,LOW);
      digitalWrite(Backward,LOW);
      ledcWrite(2, 0);
      myservo.write(45);
      i++;
      if (i == 25){
        estado = 4;  
        i = 0;
      }
      break;
    case 4:
      if (Ndis[0] <= 50){
        estado = 0;
      }
      digitalWrite(Backward,LOW);
      digitalWrite(Forward,HIGH);
      ledcWrite(2, 180);
      i++;;
      if (i == 17){
        myservo.write(132);
      }
      if (i == 25){
        estado = 5; 
        i = 0;
      }
      break;
    case 5:
      if (Ndis[0] <= 50){
        estado = 0;
      }
      myservo.write(88);
      i++;
      if (i == 10){
        estado = 6; 
        i = 0;
      }
      break;
    case 6:
      if (Ndis[0] <= 50){
        estado = 0;
      }
      myservo.write(125);
      i++;
      if (i == 20) {
        myservo.write(33);
      }
      if (i == 25){
        estado = 0; 
        i = 0;
        flagSU = false;
        flagCNE = true;
      }
      break;
  }
}

void encoder() {

  ant=act;
  
  if(digitalRead(C1)) bitSet(act,1); else bitClear(act,1);            
  if(digitalRead(C2)) bitSet(act,0); else bitClear(act,0);

  if(ant == 2 && act ==0) {n++;}
  if(ant == 0 && act ==1) {n++;}
  if(ant == 3 && act ==2) {n++;}
  if(ant == 1 && act ==3) {n++;}
  
  // Restar desplazamiento negativo
  //if(ant == 1 && act ==0) n--;
  //if(ant == 3 && act ==1) n--;
  //if(ant == 0 && act ==2) n--;
  //if(ant == 2 && act ==3) n--;    
}
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

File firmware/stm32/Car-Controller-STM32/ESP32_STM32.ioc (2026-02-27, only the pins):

Mcu.UserName=STM32F103C8Tx
PA11.Signal=USB_DM
PA12.Signal=USB_DP
PA2.Signal=USART2_TX
PA3.Signal=USART2_RX
PB6.Signal=I2C1_SCL
PB7.Signal=I2C1_SDA
PD0-OSC_IN.Signal=RCC_OSC_IN
PD1-OSC_OUT.Signal=RCC_OSC_OUT

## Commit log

2026-02-25 Add initial project structure files
    [BielaA.SLDPRT, BielaInf.SLDPRT, BielaM.SLDPRT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]
2026-02-27 Add firmware files for STM32 and ESP32 bootloader
2026-03-01 Organize files and rename them appropriately
    [BielaA.SLDPRT, BielaInf.SLDPRT, BielaM.SLDPRT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]
2026-03-01 Reorganize project files and standardize file names
    [BielaA.SLDPRT, BielaInf.SLDPRT, BielaM.SLDPRT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]
2026-03-01 Reorganize SolidWorks project structure
    [BielaA.SLDPRT, BielaInf.SLDPRT, BielaM.SLDPRT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]
